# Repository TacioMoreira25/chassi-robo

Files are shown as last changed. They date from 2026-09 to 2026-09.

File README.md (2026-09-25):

# Robô de Inspeção sobre Esteiras de Pneu MTB

Projeto de Engenharia Mecatrônica para modelagem CAD paramétrica e procedural de um **Robô de Inspeção** para áreas confinadas e terrenos industriais hostis (atendendo às normas NR-10 e NR-33), construído inteiramente em **Python** utilizando o kernel paramétrico [build123d](https://github.com/gumyr/build123d) e visualizado interativamente com o [OCP CAD Viewer](https://github.com/bernhard-42/vscode-ocp-cad-viewer).

---

## 1. Visão Geral da Arquitetura

O sistema é modular, totalmente desacoplado e 100% paramétrico:

```
chassi-robo/
├── main.py                     # Montagem global e renderização no OCP CAD Viewer
├── config.py                   # Dimensões estruturais, tolerâncias FDM e paleta de cores
├── medidas.py                  # Medidas derivadas, cálculos de offsets e dados de montagem
├── montagem.py                 # Orquestrador da montagem dos 6 subsistemas
├── pinagem_eletronica.py       # Especificação técnica de pinagem e arquitetura elétrica
├── exportar_pecas.py           # Script para exportação automatizada (.STL / .STEP)
├── modelos_cad/                # Modelos CAD oficiais em STEP dos componentes industriais
│   ├── rolamento_608zz.step    # Rolamento de esferas 608-ZZ com pistas e blindagens
│   ├── flange_acoplamento_6mm.step # Flange de alumínio 6mm com parafusos prisioneiros M3
│   ├── motor_jgb37_520.step    # Motorredutor 12V DC com redução e eixo D
│   ├── ponte_h_l298n.step      # Driver Ponte H L298N completo
│   └── step_down_lm2596_hw411.step # Módulo regulador DC-DC HW-411
├── pecas_impressas/            # Peças estruturais para manufatura aditiva (PETG)
│   ├── chassi_banheira.py      # Casco monobloco 240x160x75mm com glacis a 45°, cantos arredondados, grelhas e aletas
│   ├── tampa_superior.py       # Carenagem stealth com Cooler Fan Rise Mode 80mm, Suporte Tilt e Painel
│   ├── roda_motriz.py          # Polia motriz maciça Ø60mm com abas altas de 12mm e rebaixo para flange
│   ├── roda_livre.py           # Polias livres Ø50mm com abas altas de 12mm e alojamento duplo 608-ZZ
│   └── suporte_eletronica.py   # Bandeja interna removível com berço central para pack 3S 18650
└── pecas_mecanicas/            # Integração cinemática e circuitos
    ├── conjunto_eixo_rolamento.py # Centro de fixação da roda com rolamentos 608-ZZ e porca M8
    ├── flange_aluminio.py      # Flange metálico usinado Ø22x4mm (eixo 6mm -> M3)
    ├── motor_jgb37_520.py      # Motorredutor JGB37-520 integrado
    ├── esteira_pneu_mtb.py     # Cinta contínua oca de borracha com cravos 3D e placa de união
    └── eletronica.py           # Módulos eletrônicos (L298N, LM2596, ESP32-CAM e bateria 3S)
```

---

## 2. Especificação Elétrica e Pinagem

### Topologia de Alimentação
1. **Fonte Primária:** Pack 3S Li-Ion 18650 (11.1V nominal ~ 12.6V pico) posicionado no centro geométrico da bandeja para equilíbrio de CG.
2. **Barramento de Potência dos Motores:** Alimentação direta no borne **VMS (12V)** da Ponte H L298N.
3. **Barramento de Lógica do Microcontrolador:** Bateria 3S ligada à entrada do **Step-Down LM2596**, reduzida para **5.0V estáveis** dedicados ao pino `5V` do ESP32-CAM.
4. **Referência Comum:** GND unificado em estrela (Bateria, LM2596, ESP32-CAM e L298N).

> [!WARNING]
> O jumper de 5V do L298N deve ser desconectado se a tensão de entrada passar de 12V para proteger o regulador 78M05 interno. **Nunca alimente o ESP32-CAM pela saída 5V do L298N**, pois os surtos de corrente do rádio Wi-Fi (até 500mA) provocam quedas de tensão e *brownout reset* no microcontrolador.

### Pinagem Oficial ESP32-CAM $\rightarrow$ Ponte H L298N

| Sinal | Pino ESP32-CAM | Pino L298N | Função Mecatrônica |
| :--- | :---: | :---: | :--- |
| **Motor Esquerdo** | | | |
| `ENA` | **GPIO 14** | `ENA` | Sinal PWM de modulação de velocidade |
| `IN1` | **GPIO 12** | `IN1` | Controle de direção (Frente / Horário) |
| `IN2` | **GPIO 13** | `IN2` | Controle de direção (Ré / Anti-horário) |
| **Motor Direito** | | | |
| `ENB` | **GPIO 15** | `ENB` | Sinal PWM de modulação de velocidade |
| `IN3` | **GPIO 2** | `IN3` | Controle de direção (Frente / Horário) |
| `IN4` | **GPIO 4** | `IN4` | Controle de direção (Ré / Flash LED) |

---

## 3. Gestão Térmica e Módulo de Sensores

- **Cooler Fan Rise Mode 80mm:** Montado sob a tampa superior com recorte de Ø 75 mm e 4 furos M4 em quadrado de 71,5 x 71,5 mm, protegido por grelha integrada impressa em 3D.
- **Ventilação Cruzada:** Glacis frontal com grelhas inclinadas e aletas defletoras traseiras voltadas para baixo a 30° para expulsão passiva de ar quente protegendo contra poeira e respingos d'água.
- **Módulo Frontal Articulado Tilt (55 x 38 x 25 mm):**
  - Janela quadrada de 10 x 10 mm para câmera OV2640 (ESP32-CAM).
  - Alojamento para Sensor Térmico sem contato MLX90614 (Ø 10,2 mm).
  - 2x Faróis auxiliares Olho de Águia 12V (Ø 10,2 mm / rosca M10).
- **Painel Externo de Controle:**
  - Chave gangorra liga/desliga KCD1 iluminada (19,2 x 13,0 mm).
  - Mini voltímetro digital LED DC 0-30V (22,5 x 14,0 mm).
  - Buzzer ativo 5V (Ø 12 mm) e LED difuso vermelho 5mm de alarme térmico.
  - Conector para antena articulada SMA 2.4 GHz de 5 dBi (Ø 6,5 mm).

---

## 4. Como Executar e Visualizar

Execute o script principal:
```bash
python main.py
```
O modelo completo com seus 6 subsistemas hierárquicos e didáticos será carregado na extensão **OCP CAD Viewer** no VS Code.

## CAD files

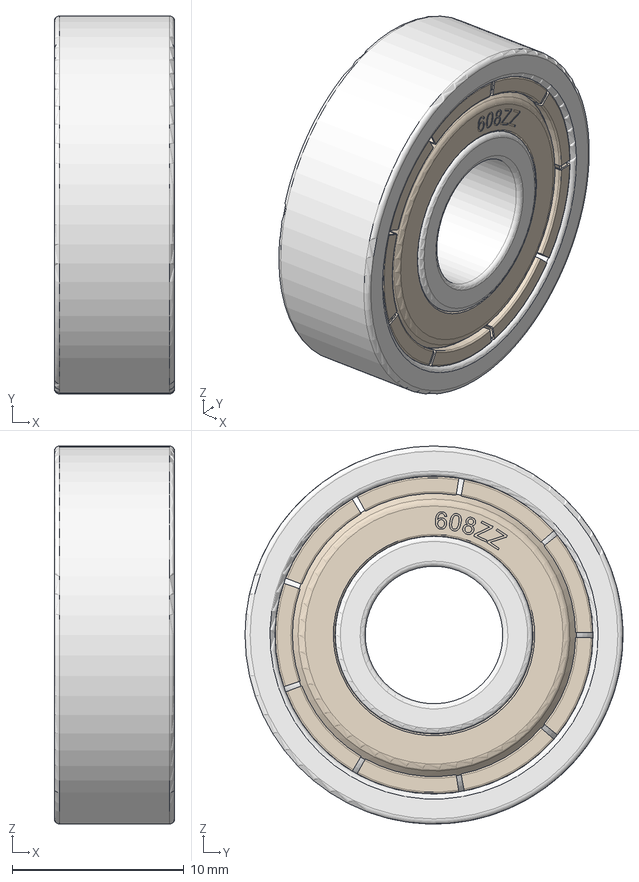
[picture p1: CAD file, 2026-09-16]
modelos_cad/rolamento_608zz.step
7.00 x 22.0 x 22.0 mm

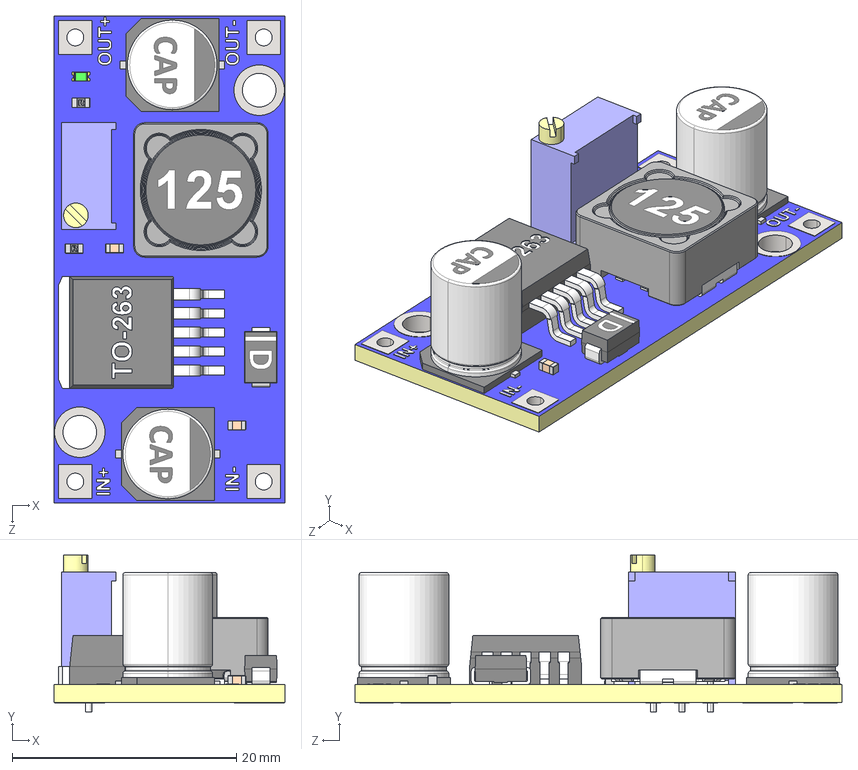
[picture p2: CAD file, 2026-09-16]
modelos_cad/step_down_lm2596_hw411.step
20.6 x 14.0 x 43.4 mm
Board^HW-411
RES_3296W^HW-411
TO-263-5^HW-411
CAP_SMD_AL_08.0x10.0^HW-411 x 2
RES_SMD_0603^HW-411 x 2
CAP_SMD_0603_H0.50^HW-411 x 2
001^CDRH125_HW-411
002^CDRH125_HW-411
005^CDRH125_HW-411 x 2
003^CDRH125_HW-411
Diode_DO214AC(SMA)^HW-411
LED_0603_Green^HW-411

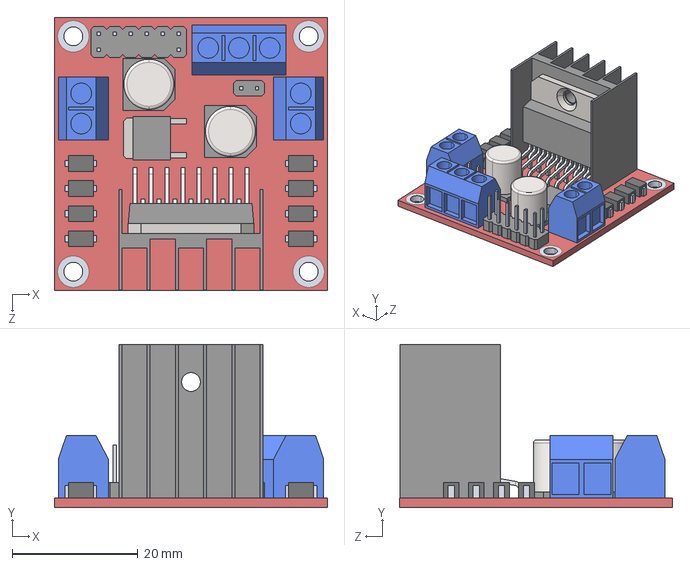
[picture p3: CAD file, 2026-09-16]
modelos_cad/ponte_h_l298n.step
43.5 x 26.0 x 43.5 mm

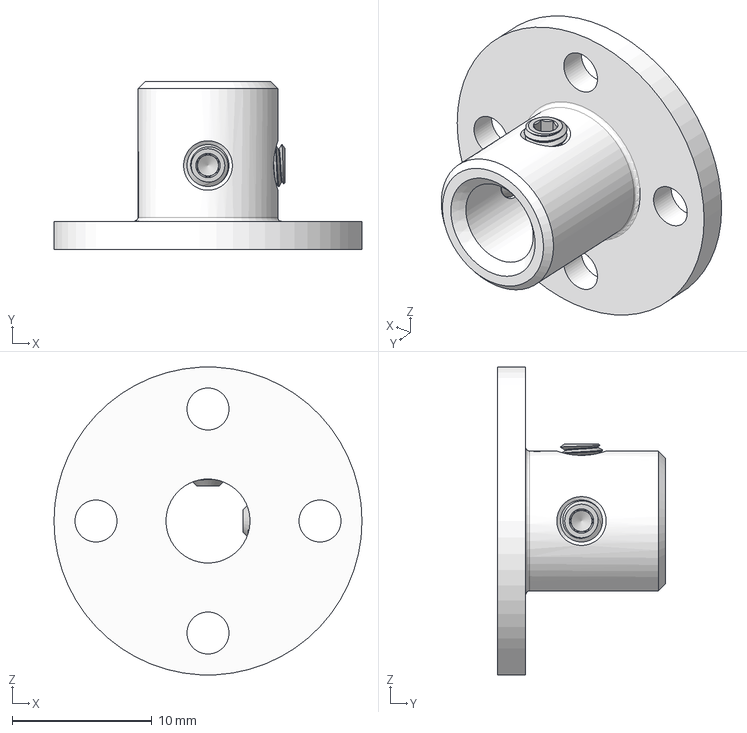
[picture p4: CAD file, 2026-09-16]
modelos_cad/flange_acoplamento_6mm.step
22.0 x 12.0 x 22.0 mm
91390A097 x 2

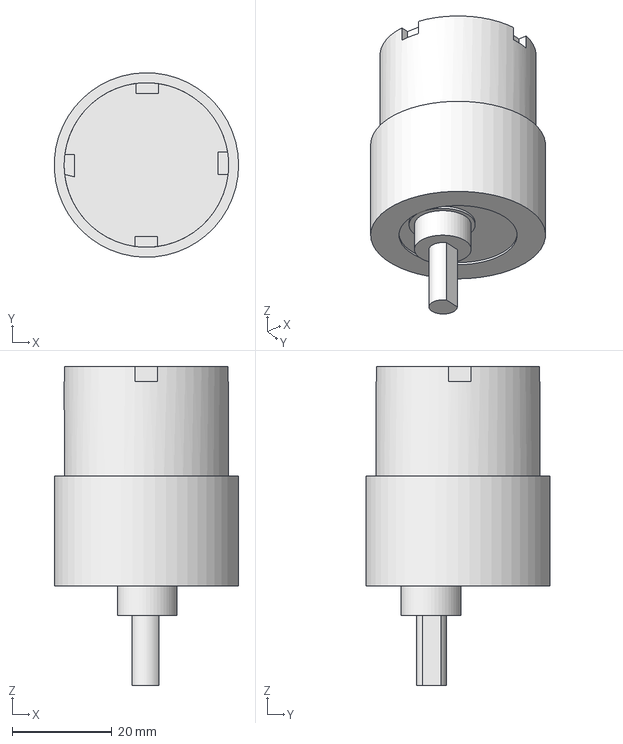
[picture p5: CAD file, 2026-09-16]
modelos_cad/motor_jgb37_520.step
37.0 x 37.0 x 64.0 mm

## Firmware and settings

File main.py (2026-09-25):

"""
===============================================================================
ROBÔ DE INSPEÇÃO - PONTO DE ENTRADA PRINCIPAL (MAIN)
===============================================================================
Projeto: Robô de Inspeção Terrestre sobre Esteiras de Pneu MTB
Visualizador: OCP CAD Viewer (Extensão VS Code)
Árvore Didática: 6 Subsistemas Principais Independentes e Numerados
===============================================================================
"""

import sys
import os
sys.path.append(os.path.abspath(os.path.dirname(__file__)))

from ocp_vscode import show, set_viewer_config
import montagem
import pinagem_eletronica as pin

def executar_visualizacao():
    print("=" * 75)
    print("       ROBÔ DE INSPEÇÃO - SISTEMA CAD PARAMÉTRICO (build123d)")
    print("=" * 75)
    
    # Exibe especificações mecatrônicas, pinagem e relatório geométrico no terminal
    pin.imprimir_relatorio_eletrico()
    import medidas
    medidas.imprimir_resumo_geometrico()
    
    print("\n[1/3] Construindo subsistemas hierárquicos e didáticos...")
    sub = montagem.montar_subsistemas()
    
    print("[2/3] Configurando iluminação e perspectiva no visualizador OCP...")
    try:
        set_viewer_config(
            default_opacity=0.92,
            grid=(True, False, False),
            axes=True,
            ortho=False
        )
        
        print("[3/3] Enviando os 6 subsistemas estruturados para o OCP CAD Viewer...")
        show(
            sub["carenagem"],
            sub["chassi"],
            sub["bandeja"],
            sub["eletronica"],
            sub["tracao_esq"],
            sub["tracao_dir"],
            names=[
                "1. Carenagem Superior Stealth (Visão + Cooler 80mm + Painel)",
                "2. Chassi Banheira (Glacis 45° + Grelhas + Aletas)",
                "3. Bandeja Interna (PETG c/ Berço Central 3S)",
                "4. Circuitos Eletronicos (L298N, LM2596, ESP32-CAM, 3S)",
                "5. Trem de Rodagem Esquerdo",
                "6. Trem de Rodagem Direito"
            ]
        )
        
        print("\n" + "=" * 75)
        print(">>> SUCESSO! Robô de Inspeção enviado ao OCP CAD Viewer com árvore didática.")
        print(">>>")
        print(">>> NAVEGAÇÃO NA BARRA LATERAL DO OCP CAD VIEWER:")
        print(">>> [1. Carenagem Superior] -> Clique no olho para ocultar a tampa e ver o interior.")
        print(">>> [2. Chassi Banheira]    -> Clique no olho para inspecionar os motores e reforços.")
        print(">>> [3. Bandeja Interna]    -> Acomodação dos módulos e berço central da bateria.")
        print(">>> [4. Circuitos]          -> L298N, LM2596, ESP32-CAM e bateria 3S 18650.")
        print(">>> [5 & 6. Trem de Rodagem]-> Polias motrizes 60mm, livres 50mm e esteiras MTB.")
        print("=" * 75)
    except Exception as err:
        print(f"\n[AVISO OCP CAD VIEWER]: {err}")
        print("Certifique-se de que a extensão OCP CAD Viewer está ativa no VS Code.")
        print("Caso ocorra erro de lock, remova ~/.ocpvscode.lock")

if __name__ == "__main__":
    executar_visualizacao()

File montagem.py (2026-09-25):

"""
===============================================================================
ROBÔ DE INSPEÇÃO - MONTAGEM GERAL DIDÁTICA E HIERÁRQUICA
===============================================================================
Engenharia Mecatrônica - Orquestração e Integração Modular no Espaço 3D
===============================================================================
Montagem rigorosamente alinhada e didática para visualização no OCP CAD Viewer:
- Subsistema 1: Carenagem Superior Stealth (Suporte Tilt + Cooler 80mm + Painel)
- Subsistema 2: Chassi Banheira Inferior (Glacis 45°, Grelhas, Aletas e Passa-Cabos)
- Subsistema 3: Bandeja Interna Eletrônica (PETG c/ Berço Central 3S)
- Subsistema 4: Circuitos Eletrônicos Embarcados (L298N, LM2596, ESP32-CAM, 3S)
- Subsistema 5: Trem de Rodagem Esquerdo (Polia Motriz 60mm, Livres 50mm, Esteira)
- Subsistema 6: Trem de Rodagem Direito (Polia Motriz 60mm, Livres 50mm, Esteira)
===============================================================================
"""

import sys
import os
sys.path.append(os.path.abspath(os.path.dirname(__file__)))

from build123d import *
import config as cfg

# Peças Estruturais Impressas (PETG)
from pecas_impressas import (
    chassi_banheira,
    tampa_superior,
    roda_livre,
    roda_motriz,
    suporte_eletronica,
)

# Componentes Mecânicos e Eletroeletrônicos
from pecas_mecanicas import (
    motor_jgb37_520,
    flange_aluminio,
    esteira_pneu_mtb,
    conjunto_eixo_rolamento,
    eletronica,
)

def montar_subsistemas() -> dict:
    """
    Gera todos os subsistemas do robô com geometria 100% alinhada e
    hierarquia limpa para a árvore lateral do OCP CAD Viewer.
    """
    alt_chassi = cfg.CONFIG["ALTURA_CHASSI"] # 75.0
    esp_parede = cfg.CONFIG["ESPESSURA_PAREDE"] # 2.5
    esp_tray = cfg.CONFIG["ESPESSURA_TRAY"] # 2.5
    alt_standoff = cfg.CONFIG["ALTURA_STANDOFF"] # 5.0

    # -------------------------------------------------------------
    # 1. CARENAGEM SUPERIOR STEALTH (TAMPA)
    # -------------------------------------------------------------
    z_borda_chassi = alt_chassi / 2.0 # 37.5mm
    tampa = tampa_superior.criar_tampa_superior().moved(Location((0, 0, z_borda_chassi)))

    # -------------------------------------------------------------
    # 2. CHASSI BANHEIRA INFERIOR (CASCO FECHADO)
    # -------------------------------------------------------------
    chassi = chassi_banheira.criar_chassi()

    # -------------------------------------------------------------
    # 3. BANDEJA INTERNA DA ELETRÔNICA
    # -------------------------------------------------------------
    z_fundo_interno = -alt_chassi / 2.0 + esp_parede + esp_tray / 2.0 # -33.75mm
    x_centro_tray = 0.0
    tray = suporte_eletronica.criar_suporte_eletronica().moved(Location((x_centro_tray, 0, z_fundo_interno)))

    # -------------------------------------------------------------
    # 4. CIRCUITOS ELETRÔNICOS EMBARCADOS (LAYOUT COM CG CENTRAL BALANCEADO)
    # -------------------------------------------------------------
    z_topo_standoff = z_fundo_interno + esp_tray / 2.0 + alt_standoff # -30.0mm

    # Pack 3S 18650 instalado no BERÇO CENTRAL GEOMÉTRICO (0, 0) para equilibrar o CG
    bateria_3s = eletronica.criar_pack_bateria_3s().moved(Location((0, 0, z_fundo_interno + esp_tray / 2.0 + 9.5)))
    bateria_3s.label = "Pack 3S 18650 (CG Central)"

    # Ponte H L298N nas torres traseiras entre os motores
    placa_l298n = eletronica.criar_ponte_h_l298n().moved(Location((-68.0, 0, z_topo_standoff + 0.8)))
    placa_l298n.label = "Ponte H L298N (12V)"

    # Regulador Step-Down LM2596 nas torres dianteiras direitas
    placa_lm2596 = eletronica.criar_step_down_lm2596().moved(Location((48.0, -32.0, z_topo_standoff + 0.8)))
    placa_lm2596.label = "Step-Down LM2596 (5V)"

    # Módulo ESP32-CAM nas torres dianteiras esquerdas
    esp32_cam = eletronica.criar_esp32_cam().moved(Location((48.0, 32.0, z_topo_standoff + 0.8)))
    esp32_cam.label = "Modulo ESP32-CAM"

    eletronica_conjunto = Compound(
        label="Eletronica Embarcada",
        children=[placa_l298n, placa_lm2596, bateria_3s, esp32_cam]
    )

    # -------------------------------------------------------------
    # 5 & 6. TREM DE RODAGEM ESQUERDO E DIREITO
    # -------------------------------------------------------------
    roda_livre_tensora_base = roda_livre.criar_roda_livre(com_abas=True)
    roda_livre_central_base = roda_livre.criar_roda_livre(com_abas=True)
    roda_motriz_base = roda_motriz.criar_roda_motriz()
    centro_m8_base = conjunto_eixo_rolamento.criar_centro_roda_m8()
    flange_base = flange_aluminio.criar_flange_aluminio()
    motor_base = motor_jgb37_520.criar_motor_jgb37()
    esteira_base = esteira_pneu_mtb.criar_esteira_mtb()

    x_motriz = cfg.CONFIG["POS_X_MOTOR"]            # -95.0mm
    x_central = cfg.CONFIG["POS_X_CENTRAL"]          # 0.0mm
    x_tensora = cfg.CONFIG["POS_X_TENSORA"]          # +95.0mm
    z_motriz = cfg.CONFIG.get("POS_Z_MOTOR", -17.5)  # -17.5mm (35mm acima do solo)
    z_eixos = cfg.CONFIG.get("POS_Z_EIXOS", -22.5)   # -22.5mm (assentadas no solo)

    larg_chassi = cfg.CONFIG["LARGURA_CHASSI"]       # 160.0mm
    larg_pista = cfg.CONFIG["LARGURA_PISTA_RODA"]    # 35.0mm
    esp_aba = cfg.CONFIG.get("ESPESSURA_ABA_RODA", 2.5) # 2.5mm
    folga_parede = 1.0                              # 1.0mm folga livre da aba à parede

    trens_tracao = {}

    for lado in ["ESQUERDO", "DIREITO"]:
        sinal_y = 1 if lado == "ESQUERDO" else -1
        esp_boss_motor = 2.0
        y_parede_int = sinal_y * (larg_chassi / 2.0 - esp_parede - esp_boss_motor)
        
        # Centro da pista da roda garantindo largura total ~230mm ponta a ponta das esteiras
        y_centro_roda = sinal_y * 98.0 # ±98.0mm (borda externa da esteira em ±115.5mm -> Largura total = 231mm)

        rot_roda = Rotation(-90, 0, 0) if lado == "ESQUERDO" else Rotation(90, 0, 0)
        rot_motor = Rotation(-90, 0, 0) if lado == "ESQUERDO" else Rotation(90, 0, 0)

        # Roda Traseira Motriz Maciça com Flange de Alumínio embutido no rebaixo
        r_m = roda_motriz_base.moved(rot_roda).moved(Location((x_motriz, y_centro_roda, z_motriz)))
        offset_flange = (larg_pista / 2.0 + esp_aba - 2.0) * sinal_y
        flange = flange_base.moved(rot_roda).moved(Location((x_motriz, y_centro_roda + offset_flange, z_motriz)))
        roda_traseira = Compound(label=f"Roda Traseira Motriz ({lado})", children=[r_m, flange])

        # Roda Central Livre de Apoio (Rolamentos e porcas embutidos no cubo)
        r_c = roda_livre_central_base.moved(rot_roda).moved(Location((x_central, y_centro_roda, z_eixos)))
        c_m8_c = centro_m8_base.moved(rot_roda).moved(Location((x_central, y_centro_roda, z_eixos)))
        roda_central = Compound(label=f"Roda Central Apoio ({lado})", children=[r_c, c_m8_c])
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

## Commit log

2026-04-05 feat: adicione arquivos de configuração e estrutura inicial do projeto
2026-04-06 feat: adicione nova estrutura de montagem e parâmetros de configuração para o chassi
2026-04-11 feat: adicione documentação e estrutura de projeto para o chassi robô
2026-08-25 Refatoração Definitiva da Geometria e Mecânica do Chassi
    - Corrigida a geometria das paredes para Trapézio Regular (Base=400, Topo=240).
    - Removidas as chapas inclinadas (front/rear). O chassi é aberto (quadro em H).
    - Adicionadas as paredes verticais de reforço nas extremidades da chapa base.
    - Corrigida a rotação dos motores Johnson (corpo para dentro, eixo para fora).
    - Substituição dos eixos passantes por parafusos M8x75mm com cabeça externa e porca/arruela interna.
    - Ajustadas as cores das catracas (pretas) e invertido o lado de montagem.
    - Reposicionado o furo da catraca dianteira superior para evitar colisão e assentar no chanfro.
    - Inseridos os furos M4 de montagem dos mo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
    [config.py, main.py, medidas.py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]
2026-08-26 feat: atualize dimensões e comentários nas configurações do chassi e ajuste de furos nas peças
2026-08-27 feat: atualizei dimensões, comentários e estrutura de montagem do chassi, incluindo novos componentes e ajustes nas peças
2026-09-16 Refactor mechanical components and electronic modules for the Iron Vanguard UGV
    [flange_acoplamento_6mm.step, motor_jgb37_520.step, ponte_h_l298n.step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]
2026-09-17 feat: update configurations and dimensions for wheels and chassis components, including new features and adjustments
2026-09-25 Refactor component descriptions and improve CAD model generation for various mechanical parts
